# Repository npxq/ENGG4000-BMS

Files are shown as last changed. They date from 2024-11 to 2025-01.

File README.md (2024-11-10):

---

# 9S LiPo Battery Management System (BMS) - Altium Project

## Project Overview
This BMS design is based on the Texas Instruments reference project [TIDA-00449](https://www.ti.com/tool/TIDA-00449). Modifications have been made to adapt the design to specific 9S LiPo battery requirements and higher current thresholds. This BMS should be capable of handling high-current applications, providing essential protections (UV, OV, SCD, OCD), enabling idle cell balancing, and displaying State of Charge via 4 LEDs. 

## Features
- **Battery Configuration**: 9S1P LiPo Battery 33.3V [3x Zeee 3S 5200mAh Lipo Battery 11.1V 80C](https://a.co/d/2pvP0it)
- **Continuous Discharge Current**: 80A
- **Maximum Discharge Current**: 120A
- **Balancing current**: 150mA at 4.2V
- **Protection Settings**:
  - **Undervoltage (UV)**: 2.75V
  - **Overvoltage (OV)**: 4.3V
  - **Overcurrent Discharge (OCD)**: 333A for 40ms (based on 80% of maximum current for a 5200mAh, 80C cell)
  - **Short-Circuit Discharge (SCD)**: 400A for 200µs
- **Components**:
  - **Analog-Front-End (AFE)**: [BQ76930](https://www.ti.com/product/BQ76930)
  - **Microcontroller (MCU)**: [MSP430G2553](https://www.ti.com/product/MSP430G2553)
  - **Balancing Circuit**: External balancing using N-channel MOSFETs
- **Communication**:
  - **AFE <--> MCU**: I2C
  - **MCU <--> External Host**: UART
  - **Programming MCU**: JTAG, Spy-Bi-Wire

## Getting Started

### Prerequisites
- Install [Git](https://git-scm.com/) on your computer.
- Set up an account on [GitHub](https://github.com/) if you haven’t already.
- Import [Celestial Altium Library](https://github.com/issus/altium-library) into Altium.

### 1. Clone the Repository
To get a copy of the project onto your local machine, open a terminal (or Git Bash if on Windows) and use the following command:

```bash
git clone <repository-url>
```

Replace `<repository-url>` with the link to this GitHub repository. This command will create a folder with all project files on your local machine.

### 2. Create a New Branch
Before making changes, it’s a good practice to create a separate branch for your work. This keeps the main codebase stable while you work on new features or fixes.

```bash
git checkout -b <branch-name>
```

Replace `<branch-name>` with a name that describes the changes you’re making (e.g., `feature-balance-circuit` or `fix-uv-protection`). 

### 3. Make Changes and Commit
After editing files, save your changes, and use the following commands to stage and commit them:

```bash
git add .
git commit -m "Brief description of your changes"
```

- `git add .` stages all modified files.
- `git commit -m` saves the changes with a message describing what you did.

You can combine the `git add` and `git commit` commands with the `-am` option, which stages and commits changes in a single command. Here’s how:

```bash
git commit -am "Brief description of your changes"
```

The `-a` option automatically stages all modified (but not new) files, and `-m` lets you add a commit message. 

#### Important Note:
This command only stages files that have already been tracked by Git (i.e., files that were previously committed). If you add any new files, you’ll need to use `git add <filename>` first or just use `git add .` to stage everything before committing.

### 4. Push Changes to GitHub
When ready to share your work, push your branch to GitHub:

```bash
git push origin <branch-name>
```

This uploads your branch to the GitHub repository, where others can see your changes.

### 5. Create a Pull Request
On GitHub, go to your repository and you’ll see an option to create a "Pull Request" (PR) for your branch. This allows others to review your changes before they’re added to the main branch.

### 6. Merging Changes
If you’re ready to combine your changes with the main branch (often after a PR review), you can merge your branch:

- First, switch back to the main branch:

  ```bash
  git checkout main
  ```

- Then, merge your changes:

  ```bash
  git merge <branch-name>
  ```

Replace `<branch-name>` with the name of your branch.

### 7. Keeping Your Branch Updated
To pull in the latest changes from the main branch into your working branch:

```bash
git checkout <branch-name>
git pull origin main
```

This keeps your branch in sync with any updates made to the main branch by others.

## Libraries and Attributions
This project utilizes components from the [Celestial Altium Library](https://github.com/issus/altium-library). Special thanks to the contributors of this open-source library for providing high-quality and accessible resources for Altium designers.

## License
**[TBD]**

---

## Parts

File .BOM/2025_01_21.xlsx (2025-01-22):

Comment | Description | Designator | Footprint | LibRef | Quantity
0.22 µF | CAP CER 0.22UF 16V X7R 0603 | C1, C4, C7, C8, C11, C14, C16, C18, C19, C20, C21 | CAP 0603_1608 | 885012206048 | 11
10 µF | CAP CER 10UF 35V X7R 1210 | C2, C5 | CAP 1210_3225 - 1MM | CL32B106KLJNNNE | 2
1 µF | CAP CER 1UF 50V X7R 0805 | C3, C6 | CAP 0805_2012 | GCJ21BR71H105KA01L | 2
4700 pF | CAP CER 4700PF 50V X7R 0603 | C9, C13 | CAP 0603_1608 | 885012206087 | 2
1 µF | CAP CER 1UF 16V X7R 0603 | C10, C15 | CAP 0603_1608 | 885012206052 | 2
4.7 µF | CAP CER 4.7UF 10V X7R 0805 | C12, C31 | CAP 0805_2012 | 885012207025 | 2
470 pF | CAP CER 470PF 50V X7R 0603 | C17 | CAP 0603_1608 | 885012206081 | 1
0.1 µF | CAP CER 0.1UF 100V X7R 0603 | C22, C24 | MURATA GRM188 0603_1608 | GRM188R72A104KA35D | 2
0.1 µF | CAP CER 0.1UF 50V X7R 0603, CAP CER 0.1UF 16V X7R 0603 | C23, C25, C26, C29, C32 | CAP 0603_1608 | 885012206095, 885012206046 | 5
0.1 µF | CAP CER 0.1UF 200V X7R 1206 | C27, C28 | CAP 1206_3216 - 0.8MM | 885342208002 | 2
2200 pF | CAP CER 2200PF 16V X7R 0603 | C30 | CAP 0603_1608 | 885012206036 | 1
1500 pF | CAP CER | C33, C36 | CAP 0603_1608 | GCD188R71H152KA01D | 2
4.7 µF | CAP TANT 4.7UF 10% 25V 1411 | C34 | CAP POL 1411_3528 | TR3B475K025C0700 | 1
10000 pF | CAP SMT06030.01UF50VDC | C35 | CAP 0603_1608 | NMC0603X7R103K50TRPF | 1
1N4148W-7-F | DIODE GEN PURP 100V 300MA SOD123 | D1, D3, D5 | SOD-123 | 1N4148W-7-F | 3
MMSZ5232BS-7-F | DIODE ZENER 5.6V 200MW SOD323 | D2, D4, D6, D7, D8, D9, D10, D11, D12, D17, D18, D19, D20, D21, D22 | SOD323 | MMSZ5232BS-7-F | 15
MMSD914T1G | DIODE GEN PURP 100V 200MA SOD123 | D13 | SOD-123 | MMSD914T1G | 1
MURS360T3G | DIODE GEN PURP 600V 3A SMC | D14 | DO214AB SMC | MURS360T3G | 1
SMCJ75A-13-F | TVS DIODE 75VWM 121VC SMC | D15 | DO214AB SMC | SMCJ75A-13-F | 1
MMSZ5246B-7-F | DIODE ZENER 16V 500MW SOD123 | D16 | SOD-123 | MMSZ5246B-7-F | 1
Green | LED GREEN CLEAR 0603 SMD | D23, D24, D25, D26 | LED 0603_1608 GREEN | 150060GS75000 | 4
BLM18SG221TN1D | Chip Ferrite Bead, 0603, 220Ω @ 100MHz, 25%, 0.04Ω, 2.5A | FB1, FB2, FB3, FB4 | FP-BLM18-0_15-t0_5-IPC_C | BLM18SG221TN1D | 4
DA-T268-101E-TR | TO-268 HEAT SINK /POLY TAPE | HS1, HS2, HS3, HS4 | FP-DA-T268-101E-TR-MFG | CMP-33535-000010-1 | 4
BATT+ | 7461147 REDCUBE Power Element Poles, 180A, Press-Fit, M5 Internal Thread, Vertical, WP-BUFU | J1 | 7461147_chemical surface | 7461147 | 1
OUT+ | 7461147 REDCUBE Power Element Poles, 180A, Press-Fit, M5 Internal Thread, Vertical, WP-BUFU | J2 | 7461147_chemical surface | 7461147 | 1
Pack 1 | CONN HEADER SMD R/A 4POS 2.5MM | J3 | FP-S4B-XH-SM4-TB_LF_SN-MFG | S4B-XH-SM4-TB | 1
BATT- | 7461147 REDCUBE Power Element Poles, 180A, Press-Fit, M5 Internal Thread, Vertical, WP-BUFU | J4 | 7461147_chemical surface | 7461147 | 1
OUT- | 7461147 REDCUBE Power Element Poles, 180A, Press-Fit, M5 Internal Thread, Vertical, WP-BUFU | J5 | 7461147_chemical surface | 7461147 | 1
M20-7820242 | CONN RCPT 2POS 0.1 GOLD PCB | J6 | HARWIN M20-7820245 | M20-7820242 | 1
M20-9760442 |  | J7 | HARWIN_M20-9760442 | M20-9760442 | 1
Pack 2 | CONN HEADER SMD R/A 4POS 2.5MM | J8 | FP-S4B-XH-SM4-TB_LF_SN-MFG | S4B-XH-SM4-TB | 1
Pack 3 | CONN HEADER SMD R/A 4POS 2.5MM | J9 | FP-S4B-XH-SM4-TB_LF_SN-MFG | S4B-XH-SM4-TB | 1
5015 | PC TEST POINT MINIATURE | J10 | FP-5015-MFG | Test Point | 1
9774050482R | 9774050482R WA-SMSI SMT Steel Spacer, M4 Internal non Stop | MP1, MP2, MP3, MP4 | 9774050482 | CMP-03913-89311597-1 | 4
DMN1019USN-7 | MOSFET N-CH 12V 9.3A SC59 | Q1, Q3, Q4, Q5, Q6, Q7, Q8, Q9, Q10 | DIODES SOT-23-3 | DMN1019USN-7 | 9
2N7002ET1G | MOSFET N-CH 60V 260MA SOT-23 | Q2, Q18 | ON SEMI SOT-23-3 | 2N7002ET1G | 2
TP0610K-T1-GE3 | MOSFET P-CH 60V 185MA SOT23-3 | Q11, Q17 | FP-S-03946-IPC_C | TP0610K-T1-GE3 | 2
STH315N10F7-6 | No Description Available | Q12, Q13, Q14, Q15 | H2PAK-6_STM | STH315N10F7-6 | 4
FDN306P | MOSFET P-CH 12V 2.6A SSOT3 | Q16 | ON SEMI SOT-23-3 | FDN306P | 1
1 kOhms | RES 1K OHM 1% 1/10W 0603, RES SMD 1K OHM 5% 1/10W 0603 | R1, R3, R7, R11, R14, R17, R18, R19, R26, R28, R32, R35, R38, R60, R67, R68, R69, R70 | RES 0603_1608 | CRCW06031K00FKEAC, CRCW06031K00JNEA | 18
100 kOhms | RES 100K OHM 1% 1/8W 0805 | R2, R8 | RES 0805_2012 | CRCW0805100KFKEAC | 2
28.7 Ohms | RES SMD 28.7 OHM 1% 1W 2512 | R4, R9, R12, R15, R20, R25, R29, R33, R36 | RES 2512_6432 | CRCW251228R7FKEG | 9
100 Ohms | RES SMD 100 OHM 1% 1/8W 0805 | R5, R39, R40, R46, R47, R48, R49, R50, R51, R52, R53, R54, R55, R56, R57 | RES 0805_2012 | CRCW0805100RFKEA | 15
10 kOhms | RES SMD 10K OHM 5% 1/10W 0603, RES 10K OHM 1% 1/10W 0603 | R6, R10, R13, R16, R21, R22, R23, R27, R31, R34, R37, R64, R65, R66, R73 | RES 0603_1608 | CRCW060310K0JNEA, CRCW060310K0FKEAC | 15
3 kOhms | RES SMD 3K OHM 5% 1/10W 0603 | R24, R71 | RES 0603_1608 | CRCW06033K00JNEA | 2
499 kOhms | RES SMD 499K OHM 1% 1/3W 0603 | R30 | RES 0603_1608 | CRCW0603499KFKEAHP | 1
1 MOhms | RES 1M OHM 5% 1/10W 0603 | R41, R42 | RES 0603_1608 | RMCF0603JT1M00 | 2
1 mOhms | RES 0.001 OHM 1% 5W 2512 | R43, R44, R45 | RES 2512_6432 | WSLF25121L000FEA | 3
100 kOhms | RES SMD 100K OHM 5% 1/10W 0603 | R58, R72 | RES 0603_1608 | CRCW0603100KJNEA | 2
154 kOhms | RES SMD 154K OHM 1% 1/3W 0603 | R59 | RES 0603_1608 | CRCW0603154KFKEAHP | 1
1.3 kOhms | RES 1.3K OHM 1% 1/10W 0603 | R61, R74, R76 | RES 0603_1608 | CRCW06031K30FKEAC | 3
110 kOhms | RES SMD 110K OHM 1% 1/10W 0603 | R62 | RES 0603_1608 | CRCW0603110KFKEB | 1
360 kOhms | RES 360K OHM 1% 1/10W 0603 | R63 | RES 0603_1608 | CRCW0603360KFKEAC | 1
31.6 kOhms | RES 31.6K OHM 1% 1/10W 0603 | R75 | RES 0603_1608 | CRCW060331K6FKEAC | 1
103AT-2 | Thermistor NTC 10KOhm 1% 2-Pin | RT1, RT2 | FP-103AT-2-MFG | 103AT-2 | 2
Low Power Mode | Switch Tactile Spst-no 0.05A 12V | S1 | 430182070816 | 430182070816 | 1
430182070816 | Switch Tactile Spst-no 0.05A 12V | S2 | 430182070816 | 430182070816 | 1
BQ7693003DBTR | IC BATT MGMT LI-ION AFE 30TSSOP | U1 | FP-DBT0030A-IPC_C | BQ7693003DBTR | 1
TPS3839G33DBZR | IC SUPERVISOR 1 CHANNEL SOT23-3 | U2 | FP-DBZ0003A-MFG | TPS3839G33DBZR | 1
MSP430G2553IPW20 | 16 MHz Mixed Signal Microcontroller with 16 KB Flash, 512 B SRAM and 24 GPIOs, -40 to 85 degC, 20-pin SOP (PW), Green (RoHS & no Sb/Br) | U3 | PW0020A_L | MSP430G2553IPW20 | 1
LMT01LPG | SENSOR DIGITAL -50C-150C TO92-2 | U4 | FP-LPG0002A-MFG | LMT01LPG | 1
LM7332MME/NOPB | Dual Rail-to-Rail Input/Output, 30V, Wide Voltage Range, High Output Operational Amplifier, 8-pin Mini SOIC, Pb-Free | U5 | DGK0008A_M | LM7332MME/NOPB | 1

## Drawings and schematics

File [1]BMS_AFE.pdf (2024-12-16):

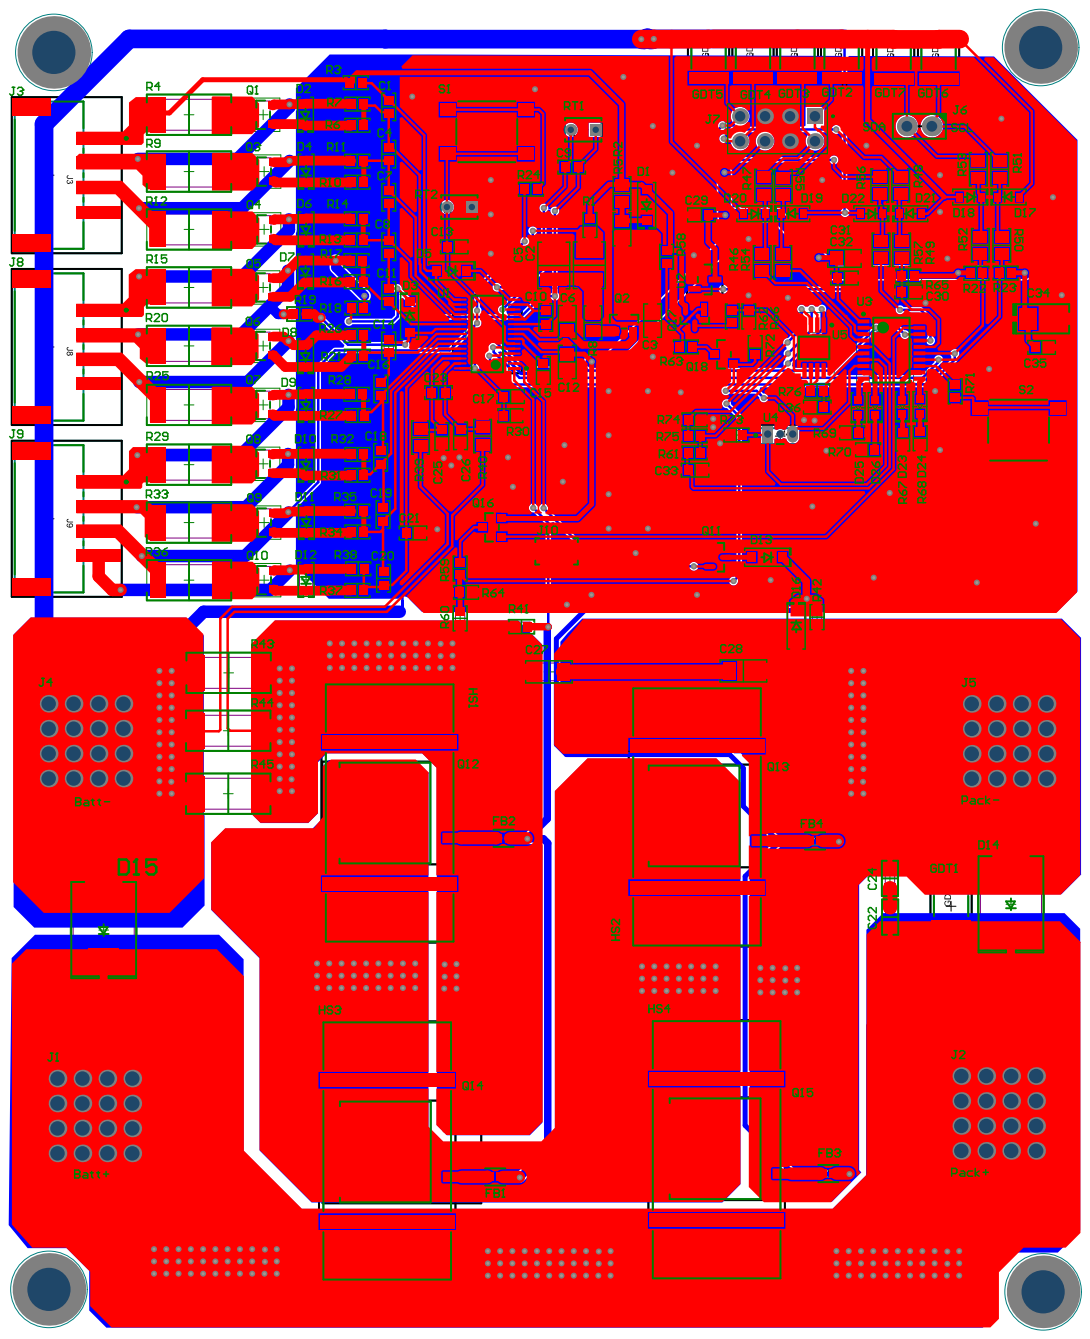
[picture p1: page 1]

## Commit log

2024-10-28 add some parts to libraries
    [BMS-BQ76930.SchDoc, BMS-lib.SchLib, BMS-pcblib.PcbLib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]
2024-10-29 add components to libraries
    [BMS-lib.SchLib]
2024-10-30 start BQ schematic
    [BMS-BQ76930.SchDoc, BMS-lib.SchLib]
2024-11-04 schematic's somewhat done
    [BMS-BQ76930.SchDoc, BMS-FETs.SchDoc, BMS-MCU.SchDoc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]
2024-11-07 Commit to rename a pcb lib
    [BMS-BQ76930.SchDoc, BMS-FETs_old.SchDoc, BMS-MCU_old.SchDoc]
2024-11-07 temporary commit to rename lib
    [BMS-MCU_old.SchDoc, BMS-lib.SchLib, ENGG4000-SysMoDEL-BMS.PrjPcb]
2024-11-07 add schematics
    [BMS_AFE.SchDoc, BMS_AFE.SchLib, BMS_FETs.SchDoc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]
2024-11-07 rm old schematics
    [BMS-FETs_old.SchDoc, BMS-MCU_old.SchDoc]
2024-11-07 still missing EC5 & JST-XH connectors, heatsink, Net-Tie footprint, sparkgap footprint, and Test Point
    [BMS-lib.SchLib, BMS_AFE.SchDoc, BMS_FETs.SchDoc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]
2024-11-08 Net-Tie might need footprint, still missing header/connector for BAT/PACK, MOSFET might need to be changed
    [BMS_AFE.SchDoc, BMS_AFE.SchLib, BMS_FETs.SchDoc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]
2024-11-08 add missing GDTs, previous commit's comments still applied
    [BMS_MCU.SchDoc]
2024-11-09 change resistor for TEMP reading
    [BMS_AFE.SchDoc, BMS_MCU.SchDoc]
2024-11-10 changed off board connection terminal
    [BMS_AFE.SchDoc, BMS_FETs.SchDoc, BMS_FETs.SchLib]
2024-12-02 PCB BMS v1
    [BMS_AFE.SchDoc, BMS_FETs.SchDoc, BMS_MCU.SchDoc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]
2024-12-03 add more BAT screw terminals and change TVS diode
    [BMS_FETs.SchDoc, ENGG4000-SysMoDEL-BMS.PrjPcb]
2024-12-04 add buffers to ADC inputs in MCU schematic, gain is still a problem
    [BMS_MCU.SchDoc, BMS_MCU.SchLib]
2024-12-05 update out-of-stock/missing-supplier-link components, fix ISENSE and PACK circuit (replace a few resistors and add LM7332 as buffer for ADC
    [BMS_AFE.SchDoc, BMS_FETs.SchDoc, BMS_MCU.SchDoc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]
2024-12-05 annotate schematic, fix FETs pin numbers
    [BMS_AFE.SchDoc, BMS_FETs.SchDoc, BMS_FETs.SchLib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]
2024-12-05 remove 4 battery screw terminals
    [BMS_FETs.SchDoc]
2024-12-12 Cell management PCB for Victory review
    [BMS_AFE.SchDoc, BMS_FETs.SchDoc, BMS_MCU.SchDoc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]
2024-12-15 fix U5's pin 8 not connected to REGOUT
    [BMS_FETs.SchDoc, BMS_MCU.SchDoc, BMS_MCU.SchLib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]
2024-12-16 minor update with C34 and C35 traces on the pcb
    [BMS_MCU.SchDoc, ENGG4000-SysMoDEL-BMS.PrjPcb]
2024-12-16 changed GDT to SparkGap
    [BMS_FETs.SchDoc, BMS_MCU.SchDoc, BMS_MCU.SchLib]
2024-12-17 Update new footprint for the 4 FETs
    [BMS_FETs.SchDoc, BMS_FETs.SchLib, ENGG4000-SysMoDEL-BMS.PrjPcb]
2024-12-20 Update: 2 layer -> 4 layer; M4 mounting holes; changed heatsinks; fixed location of U5 & U3
    [BMS_AFE.SchDoc, BMS_FETs.SchDoc, BMS_FETs.SchLib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]
2024-12-20 fixed sparkgap footprint
    [ENGG4000-SysMoDEL-BMS.PcbLib, [1]BMS_AFE.PcbDoc]
2024-12-20 Share to unb workspace
    [ENGG4000-SysMoDEL-BMS.PrjPcb]
2024-12-27 fixed E1 and modified the sparkgap footprint a little bit
    [ENGG4000-SysMoDEL-BMS.PcbLib, [1]BMS_AFE.PcbDoc]
2025-01-06 fix something
    [ENGG4000-SysMoDEL-BMS (1).PrjPcb, ENGG4000-SysMoDEL-BMS.PcbLib, [1]BMS_AFE.PcbDoc]
2025-01-06 Albert: fixed vias errors, spark gaps errors remaining
    [ENGG4000-SysMoDEL-BMS (1).PrjPcb, ENGG4000-SysMoDEL-BMS.PcbLib, [1]BMS_AFE.PcbDoc]
2025-01-07 fixed sparkgaps' un-routed net constraints, 7 short-circuit constraints remaining
    [ENGG4000-SysMoDEL-BMS.PcbLib, ENGG4000-SysMoDEL-BMS.PrjPcb, [1]BMS_AFE.PcbDoc]
2025-01-09 albert: fixed short circuit violations by adding polygon pour cutouts for through-hole components
    [BMS_AFE.SchDoc, [1]BMS_AFE.PcbDoc]
2025-01-13 Albert: re-route and re-locate the FETs Ferrite Beads to avoid cutting into polygon pours on top and bottom layers
    [[1]BMS_AFE.PcbDoc]
2025-01-20 Albert: Adjust trace widths, vias, inner layer 1; include BOM and Gerber for PCB ordering
    [2025_01_20.csv, 2025_01_20.xlsx, BMS_AFE.SchDoc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]
2025-01-20 Albert: added NC Drill to Gerber zip folder; added overlay text for pin designators + texts and logo
    [[1]BMS_AFE.PcbDoc]
2025-01-22 Albert: final touches on the overlay texts and graphics. Also generated new BOM and PickAndPlace, and Gerber for PCBA.
    [2025_01_21.csv, 2025_01_21.xlsx, 2025_01_22.xlsx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]
